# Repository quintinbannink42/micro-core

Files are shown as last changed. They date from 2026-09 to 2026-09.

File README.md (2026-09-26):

# Micro Core

Core EFI Hellen-One rusEFI ECU. Microsquirt-class sealed box, 35-way AMPSEAL, **vertical header**.

4-cylinder sequential wire-in. **STM32F407VGT6** on Hellen `mega-mcu100/0.3` (not mega-mcu64). Seven NCE4080K power FETs: 4 injector channels (2× high-Z each) plus fuel-pump, idle, and boost low-sides with US1M flyback and SMAJ33A. Gates are driven from `/V12_RAW` by SLM27524CA-DG low-side drivers, not directly from the 3.3 V GPIO.

## Status

Spec locked in [docs/SPEC.md](docs/SPEC.md). Hardware on this branch: **rev q**. Q1–Q7 are NCE4080K (LCSC C191380) on the existing DPAK land. Four SLM27524CA-DG drivers (LCSC C2921387) take the mega-mcu100 GPIO and drive the gates from `/V12_RAW` through the 12 ohm series resistors. Seven of eight channels are used; the spare input is tied to GND. Q5–Q7 (AMPSEAL pins 8/9/10, FP / Idle / Boost) keep the US1M flyback and SMAJ33A from rev p. F407VGT6 on mega-mcu100 stays. `boards/microcore-q/` lands when Create Board succeeds on `main` after merge. See [docs/HARDWARE_STATUS_rev_q.md](docs/HARDWARE_STATUS_rev_q.md). **Not production-ready.** The earlier FET comparison is in [docs/FET_COMPARISON.md](docs/FET_COMPARISON.md).

- Header: TE **776231-1** (straight / vertical)
- Plug: TE **776164-1** black, key A
- Not 776163-1 (right-angle)
- USB: vertical Mini-B on the frame (`hellen-one-common:USB_B_Mini` / `USB-MINI-B-VERTICAL`), gasketed flap or pigtail — not on the 35-way AMPSEAL

## Spec

See [docs/SPEC.md](docs/SPEC.md). Boss brief: [MICROCORE_BRIEF.md](MICROCORE_BRIEF.md).

Hellen tips: [docs/HELLEN-FAQ.md](docs/HELLEN-FAQ.md).

Firmware board name: `coreefi_micro` (sibling tree `/workspace/fw-coreefi-micro`, not in this repo). The MCU is the F407 from rev n; that firmware tree will need an F407 target later. This repo does not publish a firmware remote.

KiCad board basename: `microcore` (`BOARD_PREFIX=micro`, `BOARD_SUFFIX=core`, rev `q`).

## Hellen tooling

- Submodules: `hellen-one` (andreika-git/hellen-one), `kicad6-libraries` (rusefi/kicad6-libraries)
- CI: Create Board on push to `main`; daily submodule update workflows
- Fab outputs on main include `boards/microcore-p/`. After merge, Create Board writes `boards/microcore-q/`
- Local DRC needs **KiCad 10** (`kicad-cli`); board file is generator_version 10.0
- Empty-PCB guard: `bin/check-pcb-not-empty.sh` (Create Board job `guard-pcb-not-empty`)

## License

Hardware and docs in this repo: use for Core EFI product development.
Firmware will track rusEFI (GPL) when the board config lands.

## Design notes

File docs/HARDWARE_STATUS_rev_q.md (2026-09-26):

# Micro Core hardware status — rev q

**Date:** 2026-09-26
**Repo:** `quintinbannink42/micro-core`
**KiCad basename:** `microcore` (`BOARD_PREFIX=micro`, `BOARD_SUFFIX=core`)
**BOARD_REVISION:** **q** (fab-affecting: Q1–Q7 back to NCE4080K; four SLM27524 gate drivers on `/V12_RAW`)
**Create Board artifacts:** `boards/microcore-q/` is on `main`. Create Board has been green. This follow-up does not commit a fab pack.

## Verdict

**Not production-ready. Do not order boards.** `boards/microcore-q/` is on `main` and Create Board has been green. A human still has to look at the rev q gate-driver copper (B.Cu, U1–U4) and the GND stitch at `(131.3, 82)` before an order. Hellen DRC noise is accepted.

The electrical change is the one rev p left open: the MCU no longer drives the FET gates at 3.3 V. Each used channel is MCU GPIO to a SLM27524 input, driver output through the existing 12 ohm resistor, then the NCE4080K gate. Driver VDD is the vehicle `/V12_RAW` rail already on the board. No boost converter was added.

LS clamps from rev p are unchanged (D9–D11 US1M, D12–D14 SMAJ33A, injector D1–D8, ballast R8–R11). Frame short fixes from rev p are unchanged. Hellen module internals (M1/M2/M3) were not edited. Drill origin is still Edge.Cuts bottom-left `(107.5, 148.0872)`. `U105` stays STM32F407VGT6 on mega-mcu100.

## What landed (rev q)

### 1. Power FET: AOD4184A back to NCE4080K

Q1–Q7 are **NCE4080K**, LCSC **C191380**, footprint `microcore-fp:DPAK` (same land as rev p). Pinout stays gate, drain tab, source. AOD4184A / C99124 rows are gone from `bom_replace_microcore-q.csv`.

NCE4080K publishes RDS(on) at VGS = 10 V, not at 3.3 V. Rev q does not ask the 3.3 V GPIO to make that rating. The gate driver does.

### 2. Gate drivers

Four **Sillumin SLM27524CA-DG**, LCSC **C2921387**, SOIC-8, UCC27524 / UCC27524A class. Dual non-inverting low-side MOSFET drivers. Datasheet class: 4.5–20 V VDD, TTL/CMOS inputs (3.3 V is a valid high), about 4.5 A / 5.5 A peak. JLCPCB/LCSC had stock, so the TI UCC27524ADR alternate was not used.

Footprints are vendored as `microcore-fp:SOIC-8` and `microcore-fp:C0603` (3D models stripped). Drivers sit on **B.Cu**, next to the gate resistors. The front copper between the M1 keepout and the DPAKs does not have room for a SOIC.

| Driver | Channel | MCU net | Input | Output | Gate R | FET |
|---|---|---|---|---|---|---|
| U1 | B | `/OUT_INJ1` | pin 4 INB | pin 5 OUTB | R1 | Q1 |
| U1 | A | `/OUT_INJ2` | pin 2 INA | pin 7 OUTA | R2 | Q2 |
| U2 | B | `/OUT_INJ3` | pin 4 INB | pin 5 OUTB | R3 | Q3 |
| U2 | A | `/OUT_INJ4` | pin 2 INA | pin 7 OUTA | R4 | Q4 |
| U3 | B | `/OUT_LS1` | pin 4 INB | pin 5 OUTB | R5 | Q5 |
| U3 | A | `/OUT_LS2` | pin 2 INA | pin 7 OUTA | R6 | Q6 |
| U4 | B | `/OUT_LS3` | pin 4 INB | pin 5 OUTB | R7 | Q7 |
| U4 | A | unused | pin 2 INA tied to GND | pin 7 OUTA no-connect | — | — |

**7 of 8 channels used.** The unused input is tied low. It is not left floating.

ENA and ENB (pins 1 and 8) and VDD (pin 6) are on **`/V12_RAW`**. Driver GND (pin 3) is the same `GND` net as the FET sources. No new ground island.

Local ceramics at each VDD pin, to GND:

| Refs | Value | LCSC | Note |
|---|---|---|---|
| C1, C3, C5, C7 | 100 nF | C14663 | YAGEO CC0603KRX7R9BB104, already used on this board |
| C2, C4, C6, C8 | 1 uF 50 V X7R | **C559769** | YAGEO CC0603KRX7R9BB105. Samsung CL10A105KB8NNNC / C15849 was out of stock |

### 3. Kept from rev p

- D9–D11 US1M C112545, D12–D14 SMAJ33A C143131 on Q5–Q7. Injector D1–D8 and ballast R8–R11 unchanged.
- Frame copper short fixes (INJ3 / VR_OUT, VR_N vs drains, Q4/R9, and the rest of that pass).
- Drill origin `(107.5, 148.0872)`. Empty-PCB CI guard. ASCII-only `bom_replace` comments.
- U105 STM32F407VGT6 / mega-mcu100.

## DRC summary (kicad-cli 10.0.6)

Command: `kicad-cli pcb drc --format json --severity-all --units mm --schematic-parity`

The first rev q board matched rev p on 2026-09-26: 473 violations (207 error / 266 warning), 2 unconnected, 222 schematic-parity issues. Later passes, same checker:

- PR #11 stitched the F.Cu GND island. Unconnected 2→1. Violation count stayed 473.
- PR #12 cleared frame silk and the duplicate `/INJ1` via. Violations 473→400 (207 error / 193 warning). Unconnected stayed 1 (M2 pad S1).
- This follow-up moved Q2's reference off the M3 silk. `silk_overlap` 1→0. Violations 400→399 (207 error / 192 warning). Unconnected stays 1. Schematic parity stays 222. Hellen categories did not move. The 28 `silk_over_copper` hits are all M2 (left as later / ignore).

| Category | Now |
|---|---:|
| Total violations | 399 (207 error / 192 warning) |
| Unconnected items | 1 (M2 pad S1 vs F.Cu GND) |
| schematic_parity | 222 |
| items_not_allowed | 199 |
| padstack | 159 |
| silk_over_copper | 28 (M2 only) |
| shorting_items | 4 (Hellen pad-G pairs) |
| lib_footprint_issues | 5 |
| clearance | 2 |
| solder_mask_bridge | 1 |
| copper_edge_clearance | 1 |
| silk_overlap | 0 |
| tracks_crossing | 0 |

The items_not_allowed identity that changed in the original rev q pass is the `/OUT_INJ1` inner track. Rev p ended that trace on a via sitting on R1. Rev q removed that via (it would short the new driver-output net on the resistor pad) and shortened the trace from 3.6 mm to 2.125 mm. The remaining segment still enters the M1 keepout, which the old trace already did. Count stays 199. Hellen `items_not_allowed`, padstack, and pad-G shorts were not chased.

New copper was checked for shorts before save. The router refuses to write the board if a driver input, a driver output, or `/V12_RAW` does not join.

## Layout caveats

- Drivers and bypass caps are on B.Cu. A front SOIC does not fit between the M1 east pins and the gate resistors without sitting in the Hellen keepout.
- `/V12_RAW` is the B.Cu rail already at `(154.8, 110.4)`. A spine at x = 167.75 feeds U1–U3. That spine splits the back GND pour, so a stitch via at `(158.6, 113.0)` ties the pocket south of the spine back to the front GND zone.
- U4 is southeast of the `/INJ2` diagonal. Its VDD crosses on F.Cu between two vias, then drops back to B.Cu at the driver. Enables are tied to VDD on the chip.
- R6 (U3 OUTA) cannot cross Q3's drain on F.Cu or `/VR_N` on B.Cu. It leaves on B.Cu just west of the drain, runs In1 north of the `/VR_N` south via, and returns to F.Cu at R6.
- Inner-layer MCU tracks for the old direct gate nets were kept. The through-vias that sat on R1, R2, R4, R6, and R7 were deleted so they would not short the driver outputs. The stubs past the new taps were trimmed.
- Reference silk for U1–U3 and C1–C8 was moved so the new parts do not add silk_over_copper or silk_overlap. Q2's reference was later unlocked and moved to `(1.1, -5.1)` so it clears the M3 south silk. M3 was not edited.

## Create Board / fab path

Workflow: `.github/workflows/create-board.yaml` runs on push to `main`, then `bin/check-pcb-not-empty.sh`, then `andreika-git/hellen-one` Create Board. It applies `bom_replace_microcore-q.csv` from `revision.txt`.

`boards/microcore-q/` is already on `main`. This follow-up does not commit a fab pack. The Q2 reference move is silkscreen only (no copper, net, or drill-origin change). The next Create Board run on `main` refreshes that silk in the gerbers.

## Leftovers — before ordering boards

1. Create Board `boards/microcore-q/` and the JLC BOM confirm — **done**. `boards/microcore-q/board/microcore-q-BOM-JLC.csv` shows NCE4080K / C191380 on Q1–Q7, SLM27524CA-DG / C2921387 on U1–U4, C14663 and C559769 on the bypass caps, STM32F407VGT6 / C12345 on U105, and the clamps (US1M / C112545, SMAJ33A / C143131).
2. Residual Hellen keepout / padstack / module pad-G / edge, plus M2 silk and M2 pad S1 — **accepted / ignore**. Owner table: [DRC_TRIAGE_rev_q.md](DRC_TRIAGE_rev_q.md).
3. Human copper review of the gate-driver copper (B.Cu, U1–U4) and the GND stitch at `(131.3, 82)` — **required before order**.
4. Firmware `coreefi_micro` F407 target in the sibling tree — out of scope.
5. Optional later: `footprint_symbol_mismatch` (32) left on purpose. Writing `microcore-fp:DPAK` / `R0603` / `DO214AC` on the embedded footprint clears that parity warning, then KiCad diffs the copy against `footprints/*.kicad_mod` and adds `lib_footprint_mismatch`.

## Incident guard

Do not whole-file-replace `microcore.kicad_pcb`. Guard: `bin/check-pcb-not-empty.sh` (min 10 kB + `(zone` present). Drill origin must stay Edge.Cuts bottom-left `(107.5, 148.0872)`.

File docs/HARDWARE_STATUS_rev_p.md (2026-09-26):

# Micro Core hardware status — rev p

**Superseded by rev q (2026-09-26).** Q1–Q7 are NCE4080K again, with SLM27524CA-DG gate drivers on `/V12_RAW`. See `docs/HARDWARE_STATUS_rev_q.md`.

**Date:** 2026-09-25  
**Repo:** `quintinbannink42/micro-core`  
**KiCad basename:** `microcore` (`BOARD_PREFIX=micro`, `BOARD_SUFFIX=core`)  
**BOARD_REVISION:** **p** (fab-affecting: Q1–Q7 FET swap to AOD4184A; LS flyback + TVS; frame short fixes)  
**Create Board artifacts:** `boards/microcore-o/` is on main from rev o. **`boards/microcore-p/` after this rev is merged to `main`** (Create Board on a PR branch may run but fab files land on `main` only).

## Verdict

**Not production-ready. Do not order boards.** Quintin chose **AOD4184A** (LCSC **C99124**) and TVS on the low-side channels for budget and reliability. Rev p puts that FET on all seven DPAK lands, adds the existing cheap injector clamps to Q5–Q7, and clears the real injector / VR shorts on frame copper. Hellen module noise is still there and is listed below.

`microcore.kicad_pcb` stays substantial (F.Cu+B.Cu GND zones refilled after the diode routes and two GND stitch vias). Drill origin unchanged: Edge.Cuts bottom-left `(107.5, 148.0872)`. Core EFI silkscreen kept; letter bumped to **rev P**.

## What landed (rev p)

### 1. Power FET: NCE4080K → AOD4184A

All seven frame power FETs (Q1–Q7) are **AOD4184A**, LCSC **C99124**. Same footprint: `microcore-fp:DPAK` (TO-252 land, not redrawn). Pinout stays pin 1 gate, pin 2 drain tab, pin 3 source. Quintin picked this part for budget and reliability.

`bom_replace_microcore-p.csv` rows (ASCII comments, no ohm symbol):

`Q1`…`Q7,"AOD4184A","DPAK","C99124"`

`U105` stays `STM32F407VGT6` / `LQFP100` / `C12345` on `mega-mcu100/0.3`. Not switched to mega-mcu64.

### 2. 3.3 V gate caveat

AOD4184A is a discrete MOSFET, not a protected smart FET. No gate driver was added.

- RDS(on) max **9.5 mohm at Vgs = 4.5 V**, ID = 15 A. Not specified at 3.3 V.
- VGS(th) max **2.6 V**, so a 3.3 V MCU pin does turn the FET on.
- RDS(on) at 3.3 V is not guaranteed, especially hot and at injector or fuel-pump current.

Each gate is still the existing 12 ohm resistor (R1–R7) from the mega-mcu100 output.

### 3. Low-side flyback + TVS (Q5–Q7)

Same cheap injector-class parts already on the board. No premium clamps. No series ballast on the LS channels. Proven clamps, not extra copper protection.

| Ref | Channel | AMPSEAL | Flyback | TVS |
|---|---|---|---|---|
| Q5 | Fuel pump | pin 8 `LS1_FP` | D9 US1M C112545 | D12 SMAJ33A C143131 |
| Q6 | Idle / VVT | pin 9 `LS2_IDLE` | D10 US1M C112545 | D13 SMAJ33A C143131 |
| Q7 | Boost / spare | pin 10 `LS3_BOOST` | D11 US1M C112545 | D14 SMAJ33A C143131 |

Electrical match to Q1–Q4: flyback anode on the LS net, cathode on `/V12_RAW`; TVS cathode on the LS net, anode on GND. Parts are DO-214AC on B.Cu, north of J1. D11 is shifted to x = 152.75 so its +12 pad clears the `/VR_OUT` via at `(153.5, 111.9)`.

Two GND stitch vias, `(115.5, 105.8)` and `(144.0, 114.6)`, tie the back-side pour pockets under D12 and D13 into the front GND pour. After refill those pockets are not unconnected items.

Injector protection is unchanged: D1–D4 US1M, D5–D8 SMAJ33A, ballast R8–R11.

### 4. Frame copper shorts that this pass cleared

KiCad DRC no longer reports these rev o shorts:

- `/INJ3` on In1 jogged off `/VR_OUT` (1.0 mm track at x = 175.6; a wider jog shorted `/SGND`).
- `Net-(Q1-D)` and `Net-(Q3-D)` orthogonal segments that hit `/VR_N` removed; the drain diagonals stay.
- R9 moved to `(188, 90)` and the `/INJ2` via moved onto the new pad so `Net-(Q4-D)` no longer shorts `Net-(Q2-D)`. The Q4/R9 solder-mask bridge and the 0.05 mm clearance are gone.

## DRC summary (kicad-cli **10.0.6**)

Command: `kicad-cli pcb drc --format json --severity-all --units mm --refill-zones --save-board`

`schematic_parity` is empty (sheet and board agree). Zones were refilled after the track retarget and the stitch vias.

| Category | Count | Triage |
|---|---:|---|
| **Total violations** | **473** | 207 error / 266 warning (rev o was 467: 217 error / 250 warning) |
| items_not_allowed | 199 | Hellen module keepout (M1/M2/M3) — unchanged |
| padstack | 159 | Hellen merge noise — unchanged |
| silk_over_copper | 81 | Was 65. The extra marks are D9–D14 back silk. Not chased |
| silk_overlap | 20 | Cosmetic / module — unchanged |
| **shorting_items** | **4** | Was 10. All four left are Hellen pad G vs an empty-net pad. No injector, no `/LS*`, no new diode short |
| clearance | 2 | Both M3 pad E4 `/V5_REF` vs empty pad G. Q4/R9 clearance is gone (rev o had 5) |
| lib_footprint_issues | 5 | Vendored / Hellen |
| solder_mask_bridge | 1 | M3 pad G vs E4 only (rev o had 2; Q4/R9 bridge is gone) |
| copper_edge_clearance | 1 | M3 pad G on In2 touches Edge.Cuts |
| holes_co_located | 1 | Duplicate via leftover (Hellen) |
| **unconnected_items** | **2** | Same class as rev o: M2 pad S1 keepout vs F.Cu GND, and one F.Cu GND island. Not Q1–Q7, not D9–D14, not J1 pins 8/9/10 |
| tracks_crossing | **0** | |
| track_dangling | **0** | |
| starved_thermal | **0** | |
| courtyards_overlap | **0** | |

### Hellen noise still present (do not edit M1/M2/M3 for these)

- `/VR_OUT` F.Cu `(184.15, 83.622)`–`(186, 81.772)` vs M3 pad G `<no net>` `(186.175, 82.265)`.
- M3 pad G GND `(178.725, 75.84)` vs empty pad G `(185.925, 72.64)`.
- M1 pad G GND `(133.28119, 76.67602)` vs empty pads `(133.28119, 79.72601)` and `(137.18119, 74.12602)`.
- Clearance 0 mm: M3 PTH E4 `/V5_REF` `(193.425, 73.04)` vs empty pad G on B.Cu and In1 `(186.025, 72.7775)`. Same pair is the remaining solder-mask bridge.
- Copper edge: M3 pad G on In2 `(185.7875, 72.74)` touches Edge.Cuts.
- Unconnected: M2 pad S1 `(109.850001, 87.15)` vs F.Cu GND inside the keepout, plus one F.Cu GND island.
- items_not_allowed 199, padstack 159, lib_footprint_issues 5, holes_co_located 1.

**Not a fab order.** Create Board `boards/microcore-p/` is still required after merge. The 3.3 V gate vs 4.5 V RDS(on) caveat is still open; this rev does not add a gate driver.

## Create Board / fab path

Workflow: `.github/workflows/create-board.yaml`

1. `on: push` and `workflow_dispatch`
2. Job `guard-pcb-not-empty` runs `bin/check-pcb-not-empty.sh microcore.kicad_pcb`
3. Reuses `andreika-git/hellen-one/.github/workflows/create-board.yaml@master`, which applies `bom_replace_microcore-p.csv`

**Exact next step for CI artifacts:** merge this branch to default **`main`**. Fab files are committed by that reusable workflow **on `main` only**.

## Leftovers — before ordering boards

1. Green Create Board `boards/microcore-p/` and confirm the JLC BOM shows `AOD4184A` / `C99124` on Q1–Q7, `STM32F407VGT6` / `C12345` on `U105`, D9–D11 US1M, and D12–D14 SMAJ33A.
2. The 3.3 V gate does not have an RDS(on) spec. The datasheet number is at 4.5 V. A driver is not on this rev.
3. Residual Hellen keepout / padstack / module pad G / edge noise listed above.
4. Firmware `coreefi_micro` F407 target in the sibling tree (not this PR). This repo does not publish firmware.

## Incident guard

Do not whole-file-replace `microcore.kicad_pcb`. Guard: `bin/check-pcb-not-empty.sh` (min 10 kB + `(zone` present). Drill origin must stay Edge.Cuts bottom-left `(107.5, 148.0872)`.

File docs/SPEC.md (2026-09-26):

# Micro Core — product spec (rev P, 2026-09-24)

First Core EFI Hellen-One ECU.

**Name:** Micro Core  
**Form:** Microsquirt-class sealed box  
**Connector:** 35-way AMPSEAL, **vertical header**  
**Brain:** rusEFI Hellen-One / **STM32F407VGT6** on `mega-mcu100/0.3` (not mega-mcu64)  
**Job:** 4-cylinder sequential wire-in

## Header (locked)
**Vertical / straight pins.** Header stands off the PCB. Plug mates from above. Cable leaves the **top** of the case.

| | Part |
|---|---|
| PCB header | TE **776231-1** (35-pos AMPSEAL header, straight / vertical) |
| Mating plug | TE **776164-1** (black, key A) |
| Contacts | 1.3 mm, 17 A max |
| Orientation | AMPSEAL on the lid face, same language as V3 Microsquirt |

Do not use 776163-1 (right-angle). That puts the plug off the board edge.

Keepout: header body + plug + strain-relief is the tallest stack on the board. Route FETs and crystals away from that courtyard. Lid has a rectangular cut / well for the header flange and seal.

## Envelope
| | Target |
|---|---|
| Case L × W × H | ~120 × 80 × 42 mm including AMPSEAL height |
| Mounting | two tabs, ~107 × 54 mm centres, Ø5 mm |
| PCB | ~90 × 60 mm including header keepout |
| MAP | external |
| USB | gasketed flap or pigtail, not on the 35-way |

## AMPSEAL I/O (35 pins)
4 inj, 8 logic coils (IGN1–8), 3 PGND, 2 SGND, +12, 5 V, CLT, IAT, MAP, TPS, VR crank ±, Hall cam, CAN H/L, 2× DIN, 2× analog spare. Pins 8/9/10 are the low-side outputs (fuel pump, idle / VVT, boost / spare).

No ETB and no onboard LSU on this connector.

### Draft pin map
| Pin | Function |
|---|---|
| 1 | +12 V switched |
| 2 | CAN H |
| 3 | CAN L |
| 4–7 | Injector 1–4 |
| 8 | Fuel pump LS (Q5) |
| 9 | Idle / VVT LS (Q6) |
| 10 | Boost / spare LS (Q7) |
| 11 | DIN1 (IN_D1 / PE12) |
| 12–15 | Ignition 1–4 (5 V) |
| 16 | +5 V ref |
| 17 | TPS |
| 18 | MAP |
| 19 | Analog spare 1 |
| 20 | Sensor ground |
| 21 | Analog spare 2 |
| 22–23 | Power ground |
| 24 | CLT |
| 25 | IAT |
| 26 | DIN2 (IN_D2 / PE13) |
| 27 | Hall cam |
| 28 | VR crank + |
| 29 | VR crank − |
| 30 | IGN5 (PE2) |
| 31 | IGN6 (PB8) |
| 32 | IGN7 (PB9) |
| 33 | IGN8 (PE6) |
| 34 | SGND |
| 35 | PGND |

Core pinout, not a Microsquirt copy.

## Power stage
7× DPAK-class N-FET, all **NCE4080K** (TO-252, LCSC **C191380**) on the existing `microcore-fp:DPAK` land. The land is not redrawn. Rev q restored this FET after rev p's AOD4184A trial and added a gate driver so the 3.3 V GPIO is not the gate voltage.

Gate path, each used channel: mega-mcu100 GPIO to a **SLM27524CA-DG** input (LCSC **C2921387**, UCC27524-class dual non-inverting low-side driver), driver output through the existing 12 ohm gate resistor (R1–R7), then the FET gate. Four SOIC-8 drivers give eight channels; seven drive Q1–Q7 and U4 channel A has its input tied to GND. Driver VDD, and both enable pins, are the existing **`/V12_RAW`** rail (about 12 V on the gate). Each driver has 100 nF (C14663) and 1 uF (C559769) from VDD to the same GND as the FET sources. No boost converter.

4× injector (Q1–Q4) + SMAJ33A + US1M flyback. Two 12 ohm high-Z per channel (gate R1–R4 + ballast R8–R11). FETs on the lid-facing copper, gap-pad, clear of the AMPSEAL well.

3× low-side (Q5 fuel pump, Q6 idle / VVT, Q7 boost / spare) with gate R5–R7 at 12 ohm, plus the same cheap injector clamps per channel: US1M flyback (anode on the LS net, cathode on +12 V) and SMAJ33A (cathode on the LS net, anode on GND). No series ballast on Q5–Q7. No premium clamps. Pins 8/9/10 are those drains.

NCE4080K is a discrete MOSFET, not a protected smart FET. Its RDS(on) figure is at VGS = 10 V. The driver, not the MCU pin, is what gets the gate there. See `docs/HARDWARE_STATUS_rev_q.md`.

## Hellen modules
MCU **STM32F407VGT6** (LQFP100, LCSC **C12345**) inside Hellen `mega-mcu100/0.3`. Do not switch to `mega-mcu64`. Input lite (1× VR + Hall + analog), 4-ch Core injectors, 4-ch 5 V ign, power, 3× LS. Knock / WBO as pads or CAN.

`bom_replace_microcore-q.csv` keeps `U105` `STM32F407VGT6` / `C12345`, sets Q1–Q7 to `NCE4080K` / `C191380`, and adds U1–U4 `SLM27524CA-DG` / `C2921387` plus the VDD bypass caps. D9–D11 are US1M / C112545 and D12–D14 are SMAJ33A / C143131. C15815 and C2252 are not this MCU (op-amp and 22.1184 MHz crystal).

Firmware board: `coreefi_micro` (sibling tree `/workspace/fw-coreefi-micro`, not published from this hardware repo). That tree will need an **F407** target later; this rev does not add a firmware remote.

## Frame controls (rev K)

mega-mcu100 already has internal tactile switches (S100 nReset, S101 BOOT0). **Frame SW_BOOT / SW_RESET were removed in rev k** (schematic + PCB) so they no longer parallel those module buttons. Boot/reset on the sealed box is module-only unless a later rev adds external switches again.

## Analog / Hall conditioning (waiver — rev H)

Frame sheets `ANALOG.kicad_sch` / `HALL.kicad_sch` remain hierarchy passthrough stubs.

**Accepted for Micro Core v1:** sensor conditioning is **mega-module-only** via Hellen `mega-mcu100` input lite (1× VR + Hall + analog paths on the module). No additional frame dividers / pull-ups / ESD required for fab of the first sealed-box rev, unless a later product change reopens this.

Firmware pin freeze still follows this SPEC + `fw-coreefi-micro/connectors/main.yaml`.

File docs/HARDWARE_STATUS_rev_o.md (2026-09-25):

# Micro Core hardware status — rev o

**Superseded by rev p (2026-09-25).** Quintin chose AOD4184A (LCSC C99124) plus LS US1M flyback and SMAJ33A for budget and reliability. See `docs/HARDWARE_STATUS_rev_p.md`.

**Date:** 2026-09-22  
**Repo:** `quintinbannink42/micro-core`  
**KiCad basename:** `microcore` (`BOARD_PREFIX=micro`, `BOARD_SUFFIX=core`)  
**BOARD_REVISION:** **o** (fab-affecting: power FET swap to NCE4080K; LS Q5–Q7 and R5–R7 restored)  
**Create Board artifacts:** `boards/microcore-n/` is on main from rev n. **`boards/microcore-o/` after this rev is merged to `main`** (Create Board on a PR branch may run but fab files land on `main` only).

## Verdict

**Not production-ready.** Rev o puts NCE4080K on all seven power FETs and brings the low-side stage back. Do not order boards until Create Board produces `boards/microcore-o/` and a human accepts the gate-drive caveat below.

`microcore.kicad_pcb` stays substantial (F.Cu+B.Cu GND zones kept; refill after the LS restore is recorded below). Drill origin unchanged: Edge.Cuts bottom-left `(107.5, 148.0872)`. Core EFI silkscreen kept; letter bumped to **rev O**.

## What landed (rev o)

### 1. Power FET: VND14NV04-E → NCE4080K

All seven frame power FETs (Q1–Q7) are **NCE4080K**, LCSC **C191380**.

LCSC check (2026-09-22), page https://www.lcsc.com/product-detail/C191380.html :

| ID | What LCSC lists | Used? |
|---|---|---|
| **C191380** | NCE **NCE4080K**, MOSFET N-CH 40 V 80 A, package **TO-252-2L**, in stock (page showed about 21,877) | **Yes** |

Datasheet (LCSC PDF, NCE V2.0): VDS 40 V, ID 80 A, VGS ±20 V, VGS(th) 1.2 / 1.8 / 2.5 V (min / typ / max) at ID = 250 µA, RDS(on) < 7 mΩ at VGS = 10 V and ID = 20 A. No RDS(on) row at 4.5 V or 2.5 V.

`bom_replace_microcore-o.csv` rows (ASCII comments, no ohm symbol):

`Q1`…`Q7,"NCE4080K","DPAK","C191380"`

`U105` stays `STM32F407VGT6` / `LQFP100` / `C12345` on `mega-mcu100/0.3`. Not switched to mega-mcu64.

### 2. Footprint: existing DPAK land fits TO-252-2L

PCB footprint is still `microcore-fp:DPAK` (file `footprints/DPAK.kicad_mod`). It is a 2-lead + tab pattern, not a 3-lead gullwing:

| | Existing `DPAK` | LCSC EasyEDA land for C191380 (`TO-252-2_L6.6-W6.1-P4.57-LS9.9-BR-CW`) |
|---|---|---|
| Lead pitch | 4.56 mm (pads at y = ±2.28 mm) | **P4.57** (4.57 mm) |
| Lead pads | 2.2 × 1.2 mm | about 3.0 × 1.6 mm |
| Tab (drain) | 6.4 × 5.8 mm | about 6.2 × 5.8 mm |

Package body from the NCE drawing: lead width b = 0.66–0.86 mm, basic pitch e = 2.186–2.386 mm (JEDEC; the 2L part keeps the outer leads, so the span is about 2×e). The datasheet note says the lead pitch follows JEDEC. Pinout on the LCSC symbol is pin 1 Gate, pin 2 Drain (tab), pin 3 Source. That matches the footprint pads and the schematic symbol pin numbers already used for the old smart FET (1 = input/gate, 2 = drain, 3 = source).

The lead is narrower than the 1.2 mm pad. The lead pad is smaller than LCSC’s recommended land, and the pitch and tab match, so the footprint was **not** redrawn. Routing that already landed on these pads stays put.

### 3. Seven FETs: Q5–Q7 and R5–R7 restored

Rev n deleted the low-side stage. Rev o puts it back from the pre-rev-n sheet and copper:

| Ref | Role | Gate | AMPSEAL |
|---|---|---|---|
| Q5 | Fuel-pump LS | R5, 12 ohm | pin 8 `LS1_FP` |
| Q6 | Idle / VVT LS | R6, 12 ohm | pin 9 `LS2_IDLE` |
| Q7 | Boost / spare LS | R7, 12 ohm | pin 10 `LS3_BOOST` |

`LS3.kicad_sch` is the three-channel sheet again (hierarchical IN1–IN3 / OUT1–OUT3). Root sheet name is `LS3` (not `LS3-NC`). MCU labels `OUT_LS1` / `OUT_LS2` / `OUT_LS3` connect to the gates through R5–R7. J1 pads 8/9/10 carry `/LS1_FP` `/LS2_IDLE` `/LS3_BOOST` again.

LS still has **no** flyback diode and **no** TVS. That matches the pre-rev-n sheet (the note there already said flyback/TVS were injector-only). Injector protection is unchanged: D1–D4 US1M, D5–D8 SMAJ33A, ballast R8–R11, all on Q1–Q4.

### 4. NCE4080K is not a protected smart FET — gate drive caveat

VND14NV04-E was a logic-level protected low-side (current limit, thermal shutdown, internal clamp) that a 3.3 V MCU can drive directly. NCE4080K is a plain trench MOSFET.

- **The schematic is complete without a gate driver.** VGS(th) max is 2.5 V, and the MCU pin is 3.3 V, so the FET does turn on. Each gate is the existing 12 ohm series resistor (R1–R7) from the mega-mcu100 output. No driver, charge pump, or extra transistor was added.
- **The 7 mΩ rating does need ~10 V if you want that RDS(on).** The datasheet gives RDS(on) only at VGS = 10 V. At 3.3 V the worst-case device is 0.8 V above threshold. On-resistance at 3.3 V is not specified and will be higher than 7 mΩ, especially hot and at injector or fuel-pump current. A gate driver to about 10 V, or a different MOSFET with RDS(on) rated at 4.5 V or below, is required before this is a reliable power stage. That driver is **not** on this rev.
- **No internal clamp.** Injector channels still have US1M flyback and SMAJ33A. The three LS channels do not. Fuel-pump, idle, and boost solenoids are inductive. The only voltage limit on those drains is the 40 V FET itself.

## DRC summary (kicad-cli **10.0.6**)

Command: `kicad-cli pcb drc --format json --severity-all --units mm --refill-zones --save-board`

F.Cu+B.Cu GND zones were refilled after Q5–Q7 and R5–R7 were put back, so the new gate and drain pads are cleared out of the pour and the source pads sit on GND. Fill diff is polygon geometry. Footprints, drill origin `(107.5, 148.0872)`, and zone outlines were not moved. `schematic_parity` is empty (sheet and board agree).

| Category | Count | Triage |
|---|---:|---|
| **Total violations** | **467** | 217 error / 250 warning (rev n was 456: 217 / 239; rev m was 469: 219 / 250) |
| items_not_allowed | 199 | Hellen module keepout (M1/M2/M3) — merge noise |
| padstack | 159 | Hellen merge noise |
| silk_over_copper | 65 | Back to the rev m count; LS ref silk is on the board again (rev n was 56) |
| silk_overlap | 20 | Cosmetic / module (rev n was 18) |
| **shorting_items** | **10** | Same count as rev n. **No LS net** (`/LS*`, `Net-(Q5-IN)` …) |
| clearance | 5 | FET cluster / merge; same class as rev n |
| lib_footprint_issues | 5 | Vendored / Hellen |
| solder_mask_bridge | 2 | Same class as rev n (Q4/R9 injector side, not the restored LS FETs) |
| copper_edge_clearance | 1 | Edge |
| holes_co_located | 1 | Duplicate via leftover (Hellen) |
| **unconnected_items** | **2** | M2 pad S1 keepout vs F.Cu GND; one F.Cu GND island. **Not** Q5–Q7 and **not** J1 pins 8/9/10 |
| tracks_crossing | **0** | |
| via_dangling | **0** | |

### Shorts still present (rev n / rev m leftovers, not this pass)

- `/INJ3`↔`/VR_OUT` on In1 (Hellen leftover fanout vs VR).
- `/VR_N`↔`Net-(Q1-D)` and `/VR_N`↔`Net-(Q3-D)`.
- `Net-(Q4-D)`↔`Net-(Q2-D)` (injector ballast, not Q5–Q7).
- GND or `/VR_OUT` vs an empty-net module pad.

No short names `/LS1_FP`, `/LS2_IDLE`, `/LS3_BOOST`, or `Net-(Q5-IN)` / `Q6` / `Q7`.

Q5 pads after refill: gate `Net-(Q5-IN)`, drain `/LS1_FP`, source `GND`. Q6/Q7 follow the same pattern (idle, boost).

**Not a fab order yet.** Create Board `boards/microcore-o/` and a human decision on 3.3 V gate drive vs the 10 V RDS(on) rating are still required. The DRC blockers above are the preexisting Hellen merge / injector-VR shorts, not the FET swap or the restored LS stage.

## Create Board / fab path

Workflow: `.github/workflows/create-board.yaml`

1. `on: push` and `workflow_dispatch`
2. Job `guard-pcb-not-empty` runs `bin/check-pcb-not-empty.sh microcore.kicad_pcb`
3. Reuses `andreika-git/hellen-one/.github/workflows/create-board.yaml@master`, which applies `bom_replace_microcore-o.csv`

**Exact next step for CI artifacts:** merge this branch to default **`main`**. Fab files are committed by that reusable workflow **on `main` only**.

## Leftovers — before ordering boards

1. Green Create Board `boards/microcore-o/` and confirm the JLC BOM shows `NCE4080K` / `C191380` on Q1–Q7, `STM32F407VGT6` / `C12345` on `U105`, and R5–R7 present.
2. Decide the 3.3 V gate vs 10 V RDS(on) question (driver, or a logic-level FET) before relying on injector or fuel-pump current. Comparison and recommendation (keep NCE4080K; DMTH4004LK3 is the wrong swap at 3.3 V): [FET_COMPARISON.md](FET_COMPARISON.md).
3. LS inductive loads have no external clamp.
4. Residual Hellen keepout / padstack noise and the preexisting injector-VR shorts called out on rev n.
5. Firmware `coreefi_micro` F407 target in the sibling tree (not this PR). This repo does not publish firmware.

## Incident guard

Do not whole-file-replace `microcore.kicad_pcb`. Guard: `bin/check-pcb-not-empty.sh` (min 10 kB + `(zone` present). Drill origin must stay Edge.Cuts bottom-left `(107.5, 148.0872)`.

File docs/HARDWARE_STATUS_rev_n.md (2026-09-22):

# Micro Core hardware status — rev n

**Date:** 2026-09-22  
**Repo:** `quintinbannink42/micro-core`  
**KiCad basename:** `microcore` (`BOARD_PREFIX=micro`, `BOARD_SUFFIX=core`)  
**BOARD_REVISION:** **n** (fab-affecting: F407 BOM swap on mega-mcu100; remove LS FET stage)  
**Create Board artifacts:** last packages on main include `boards/microcore-m/`. **`boards/microcore-n/` after this rev is merged to `main`** (Create Board on a PR branch may run but fab files land on `main` only).

## Verdict

**Not production-ready.** Cost-down rev n keeps Hellen `mega-mcu100/0.3` and swaps the module MCU from STM32F429VIT6 to STM32F407VGT6. The frame low-side FET stage is removed. Do not order boards until Create Board produces `boards/microcore-n/` and a human reviews the JLC BOM line for `U105`.

`microcore.kicad_pcb` stays substantial (filled F.Cu+B.Cu GND zones still present). Drill origin unchanged: Edge.Cuts bottom-left `(107.5, 148.0872)`. Core EFI silkscreen kept; letter bumped to **rev N**.

## What landed (rev n)

### 1. MCU: F429 → F407, same mega-mcu100

Module symbol stays `Module:mega-mcu100/0.3` / footprint `hellen-one-mega-mcu100-0.3:mega-mcu100`. Not switched to mega-mcu64.

`bom_replace_microcore-n.csv` row:

`U105,"STM32F407VGT6","LQFP100","C12345"`

Replaces `STM32F429VIT6` / LCSC `C92002` (the `U105` line in `boards/microcore-m/board/microcore-m-BOM-JLC.csv`).

LCSC check (2026-09-22):

| ID | What LCSC/JLCPCB actually lists | Used? |
|---|---|---|
| **C12345** | ST **STM32F407VGT6**, LQFP-100(14x14), 1 MB flash, in stock (LCSC showed 1601) | **Yes** |
| C15815 | TI TLC2252CDR op-amp, SOP-8 | No |
| C2252 | YXC 22.1184 MHz crystal, HC-49S-SMD | No |

Firmware board name remains `coreefi_micro`. Sibling tree `/workspace/fw-coreefi-micro` will need an F407 target later. This hardware repo does not add a firmware remote.

### 2. Four injector FETs only

Kept: Q1–Q4, gate R1–R4, ballast R8–R11, flyback D1–D4 (US1M), TVS D5–D8 (SMAJ33A).

Removed from schematic (`LS3.kicad_sch` is now a stub, root sheet `LS3-NC` has no pins) and from the PCB (footprints, tracks, vias, ref silk):

| Was | Role | Gate resistor |
|---|---|---|
| Q5 | Fuel-pump LS | R5 |
| Q6 | Idle / VVT LS | R6 |
| Q7 | Boost / spare LS | R7 |

Copper deleted with those parts (no remaining segments or vias):

- `/LS1_FP`, `/LS2_IDLE`, `/LS3_BOOST` (drains to AMPSEAL)
- `Net-(Q5-IN)`, `Net-(Q6-IN)`, `Net-(Q7-IN)` (gate side of R5–R7)
- `/OUT_LS1`, `/OUT_LS2`, `/OUT_LS3` tracks and vias

mega-mcu100 pads E18/E19/E20 still carry nets `/OUT_LS1` `/OUT_LS2` `/OUT_LS3` (module pins OUT_PWM1/2/3). Those pads are the module footprint, not traces to the removed FETs. J1 pads 8/9/10 have the LS nets cleared (connector pin copper only, no tracks).

No explicit GND track ended on the Q5–Q7 source pads (sources were on the GND pour). Diode GND stubs at x=195.1 (rev m) were left in place.

`bom_replace_microcore-n.csv` drops the Q5–Q7 and R5–R7 rows. Comments are ASCII-only.

### 3. AMPSEAL pins 8/9/10

| Pin | rev m | rev n |
|---|---|---|
| 8 | Fuel pump LS | Reserved / NC (unstuffed LS — future option) |
| 9 | Idle / VVT LS | Reserved / NC (unstuffed LS — future option) |
| 10 | Boost / spare LS | Reserved / NC (unstuffed LS — future option) |

Schematic: local labels `LS1_FP` / `LS2_IDLE` / `LS3_BOOST` removed from J1; `no_connect` on those pins.

## DRC summary (kicad-cli **10.0.6**)

Command: `kicad-cli pcb drc --format json --severity-all --units mm --refill-zones --save-board`

F.Cu+B.Cu GND zones were refilled after the LS deletion. Fill diff is polygon geometry only (footprints, drill origin, and zone outlines unchanged).

| Category | Count | Triage |
|---|---:|---|
| **Total violations** | **456** | 217 error / 239 warning (rev m was 469: 219 / 250) |
| items_not_allowed | 199 | Hellen module keepout (M1/M2/M3) — merge noise |
| padstack | 159 | Hellen merge noise |
| silk_over_copper | 56 | Was 65 on rev m (LS ref silk gone) |
| silk_overlap | 18 | Cosmetic / module |
| **shorting_items** | **10** | Was 12 on rev m. **No LS net** (`/LS*`, `Net-(Q5-IN)` …) remains |
| clearance | 5 | FET cluster / merge; not the removed LS stage |
| lib_footprint_issues | 5 | Vendored / Hellen |
| solder_mask_bridge | 2 | Same class as rev m (not the removed FETs) |
| copper_edge_clearance | 1 | Edge |
| holes_co_located | 1 | Duplicate via leftover (Hellen), same class as rev m |
| **unconnected_items** | **2** | M2 pad S1 keepout vs F.Cu GND; one F.Cu GND island. **Not** J1 pins 8/9/10 |
| tracks_crossing | **0** | |
| via_dangling | **0** | LS vias removed with their nets |

### Shorts still present (rev m leftovers, not this pass)

- `/INJ3`↔`/VR_OUT` on In1 (Hellen leftover fanout vs VR).
- `/VR_N`↔`Net-(Q1-D)` and `/VR_N`↔`Net-(Q3-D)`.
- `Net-(Q4-D)`↔`Net-(Q2-D)`.
- GND or `/VR_OUT` vs an empty-net module pad.

No short names `/LS1_FP`, `/LS2_IDLE`, `/LS3_BOOST`, or `Net-(Q5-IN)` / `Q6` / `Q7`.

**Not a fab order yet.** Create Board `boards/microcore-n/` and a human look at the JLC `U105` line are still required. The DRC blockers above are the preexisting Hellen merge / injector-VR shorts, not the F407 swap or the removed LS stage.

## Create Board / fab path

Workflow: `.github/workflows/create-board.yaml`

1. `on: push` and `workflow_dispatch`
2. Job `guard-pcb-not-empty` runs `bin/check-pcb-not-empty.sh microcore.kicad_pcb`
3. Reuses `andreika-git/hellen-one/.github/workflows/create-board.yaml@master`, which applies `bom_replace_microcore-n.csv`

**Exact next step for CI artifacts:** merge this branch to default **`main`**. Fab files are committed by that reusable workflow **on `main` only**.

## Leftovers — before ordering boards

1. Green Create Board `boards/microcore-n/` and confirm JLC BOM shows `STM32F407VGT6` / `C12345` on `U105`, and that Q5–Q7 / R5–R7 are absent.
2. Residual Hellen keepout / padstack noise and the preexisting In1 `/INJ3`↔`/VR_OUT` short (rev m leftover). Zone refill for this rev is already in the board file.
3. Firmware `coreefi_micro` F407 target in the sibling tree (not this PR).

## Incident guard

Do not whole-file-replace `microcore.kicad_pcb`. Guard: `bin/check-pcb-not-empty.sh` (min 10 kB + `(zone` present). Drill origin must stay Edge.Cuts bottom-left `(107.5, 148.0872)`.

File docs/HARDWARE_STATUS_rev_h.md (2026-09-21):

> **Superseded for current work:** see [HARDWARE_STATUS_rev_m.md](HARDWARE_STATUS_rev_m.md) (rev m: D1–D8 collector re-route).

# Micro Core hardware status — rev h → i

**Date:** 2026-09-21 (UTC+2)  
**Repo:** `quintinbannink42/micro-core` @ `main`  
**KiCad basename:** `microcore` (`BOARD_PREFIX=micro`, `BOARD_SUFFIX=core`)  
**BOARD_REVISION:** **i** (PCB content change this pass: J8 GND stitch). Rev **h** was restore + Edge.Cuts origin `(107.5, 148.0872)`.  
**Create Board artifacts:** last green `boards/microcore-i/` (CI run 35559694730 success).

## Verdict

**Not fab-ready.** J8 GND stitch and FET/gate LCSC assigns landed; injector/LS flyback+TVS (+ second 12 Ω high-Z) still missing from schematic/PCB; remaining DRC noise is mostly Hellen keepout / empty-net module-pad merge.

## DRC summary (kicad-cli **10.0.6**)

Command: `kicad-cli pcb drc --format report --severity-all --output … microcore.kicad_pcb`  
(Board is KiCad 10 format; Debian kicad 9.0.2 cannot load it.)

### vs prior status (rev g doc, KiCad 9.0.2 on pre-merge style counts)

| Category | Rev g (K9 doc) | Rev i after J8 stitch (K10) | Notes |
|---|---:|---:|---|
| Total DRC violations | (large; mixed cats) | **425** | Different checker/taxonomy under K10 |
| shorting_items | **147** | **4** | No mass GND↔SGND pairs under K10; remaining = empty-net module pad G vs signal/GND |
| unconnected_items | **2** (zone island + **J8 GND**) | **1** | **J8 cleared**; leftover = F.Cu GND zone ↔ M2 pad S1 inside module keepout (copperpour/tracks not_allowed) — treat as Hellen-merge false positive unless copper review says otherwise |
| padstack | 159 | 159 | Unchanged Hellen merge noise |
| items_not_allowed | (n/a in g doc) | 199 | Keepout / local override tracks in module keepouts |
| silk_* | ~51 | 43 | Cosmetic |
| clearance | 28 | 12 | Improved vs g doc |

Top shorting leftovers (4): `/VR_OUT`↔empty M3 pad G; GND↔empty M1/M3 pad G. **Not** GND↔`/SGND` pairs in this K10 report.

## Must-list vs `docs/SPEC.md` (Boss brief)

| # | Item | Status after this pass |
|---|---|---|
| 1 | GND↔SGND shorts / AMPSEAL fanout | **Mostly cleared under K10 DRC** (0 GND↔SGND short pairs). Residual empty-net module-pad shorts + AMPSEAL fanout still need human copper eye before claiming clean. |
| 2 | J8 GND ↔ zone connectivity | **Fixed on PCB (rev i):** GND via @ `(114.9, 79.5)` + F.Cu tracks from J8 pads 5/6 (L-path on pad 6L to clear VBUS). J8 no longer in unconnected set. |
| 3 | SMBJ33A + UF flyback (+ 2×12 Ω) on INJ4/LS3 + bom_replace/LCSC | **BLOCKER — not fab-ready.** Sheets still text-only “flyback/TVS TBD”. Only **1×12 Ω gate** per channel on sch/PCB (`R1–R7`). No DO-214/SMA in `footprints/`; FET cluster packed. Do **not** fake parts. Needs layout pass (or SPEC change). |
| 4 | ANALOG + HALL conditioning | **Waived** — mega-module-only input lite written into `docs/SPEC.md` + this status. Frame stubs stay passthrough. |
| 5 | Q1–Q7 + gate Rs on JLC BOM with LCSC | **Done on `boards/microcore-i/` JLC BOM:** Q1–Q7=`C155647`, R1–R7=`C22783`. |
| 6 | Create Board after PCB change; bump revision | **BOARD_REVISION=i**; Create Board **green** → `boards/microcore-i/`. |

## Inventory

| Area | Present |
|---|---|
| Last green board package | `boards/microcore-i/` gerber/BOM/CPL/ibom/png/pdf |
| Pending | `boards/microcore-i/` after CI |
| Frame FETs Q1–Q7 + R1–R7 | On sch+PCB; LCSC via bom_replace (i) |
| Flyback/TVS | **Absent** |

## Decision hold (Boss)

Flyback/TVS layout vs SPEC defer is with Quintin via Boss — **do not start either path** until Boss confirms.

## Leftovers — **fab-ready** (must) — for Boss

1. **Add SMBJ33A + UF flyback per INJ/LS channel** (and second 12 Ω high-Z where SPEC requires) to schematic **and** PCB, with LCSC / `bom_replace` — or explicitly revise SPEC. **True layout blocker** (space + footprints).  
2. Human copper pass on residual **empty-net module pad G** shorts / AMPSEAL fanout (and confirm M2 S1 keepout unconnected is acceptable).  
3. ~~Confirm Create Board `boards/microcore-i/`~~ — **done** (green; Q/R on JLC BOM).

## Leftovers — nice-to-have

1. LCSC duplicate-partnumber warnings (100n / BAT54S).  
2. Silk cleanup.  
3. Title-block still says rev C in places.  
4. Diff-pair VR_P/VR_N noise.

## Quick safe fixes done this pass

- KiCad 10 DRC on current PCB; compared to rev-g status counts.  
- J8 GND via+track stitch (rev **i**).  
- `bom_replace_microcore-i.csv` LCSC for Q1–Q7 + R1–R7.  
- ANALOG/HALL mega-module-only waiver in SPEC.  
- README → microcore-i (last green); this status doc.  
- Kept incident note below.

**PCB content changed** → revision **i**.

## Incident: empty PCB on main (ce63db4)

Commit `ce63db4` (“Fix drill origin…”) **wiped** `microcore.kicad_pcb` to ~49 bytes (16063 lines → 1). Cause: an edit that replaced the whole file instead of only changing `aux_axis_origin` / `grid_origin`. Restored from `298ebd5` (rev h content) and set drill/place origin to Edge.Cuts bottom-left `(107.5, 148.0872)` (Hellen practice: Y grows downward → bottom-left = `(min_x, max_y)`). Guard: `bin/check-pcb-not-empty.sh` + Create Board job `guard-pcb-not-empty`.

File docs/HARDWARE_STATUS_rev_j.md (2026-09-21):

> **Superseded for current work:** see [HARDWARE_STATUS_rev_m.md](HARDWARE_STATUS_rev_m.md) (rev m: D1–D8 collector re-route).

# Micro Core hardware status — rev j

**Date:** 2026-09-21  
**Repo:** `quintinbannink42/micro-core`  
**KiCad basename:** `microcore` (`BOARD_PREFIX=micro`, `BOARD_SUFFIX=core`)  
**BOARD_REVISION:** **j** (fab-affecting: injector TVS + UF flyback + 2nd 12 Ω per INJ channel on sch+PCB)  
**Create Board artifacts:** last green `boards/microcore-h/`; `boards/microcore-i/` may appear from CI on `main`; **`boards/microcore-j/` after this rev is merged to `main`**.

## Verdict

Injector SPEC power-stage protection is now on schematic and PCB (real `DO214AC` footprints). **Not a fab order yet** until Create Board produces `boards/microcore-j/` and a human copper pass reviews the new alley / pocket-C parts against AMPSEAL keepout. Residual DRC is still expected Hellen keepout / empty-net module-pad merge (same class as rev i).

`microcore.kicad_pcb` remains substantial (~673 kB, 4 zones, 33 footprints). Drill origin unchanged: Edge.Cuts bottom-left `(107.5, 148.0872)`.

## What landed (rev j)

Per injector channel 1–4 (`INJ4.kicad_sch` + PCB):

| Ref | Function | Package | LCSC (`bom_replace_microcore-j.csv`) |
|---|---|---|---|
| R1–R4 | existing 12 Ω gate | R0603 | C22783 |
| R8–R11 | **2nd 12 Ω high-Z ballast** (FET drain → AMPSEAL `/INJn`) | R0603 | C22783 |
| D1–D4 | **US1M UF flyback** (anode `/INJn`, cathode `/V12_RAW`) | DO-214AC / SMA | C112545 |
| D5–D8 | **SMAJ33A** 33 V unidirectional TVS (cathode `/INJn`, anode GND) — DO-214 equivalent of SMBJ33A | DO-214AC / SMA | C143131 |

SMAJ33A is the SMA (DO-214AC) equivalent of SMBJ33A (SMB / DO-214AA), chosen so the FET cluster did not have to grow into the AMPSEAL courtyard. Electrical clamp is the same 33 V unidirectional TVS family.

LS3 (Q5–Q7) still has gate 12 Ω only. SPEC power-stage text is **4× injector** DPAK + TVS + UF + 2×12 Ω; LS flyback was not added.

### PCB placement (FET cluster not exploded)

Moving Q1–Q7 south/east would enter AMPSEAL courtyard (`J1` TE_776231 @ `(152.2, 129.99)`, silk ±38.45 × ±16.05 → north ~y=113.94) or the board edge. Cluster left in place; new parts use empty pockets:

- **R8–R11** at the SW corner of Q1–Q4; existing drain vias nudged off the DPAK tab so the ballast is the only drain↔`/INJ` link (`Net-(Qn-D)` vs `/INJn`).
- **D1–D4 (US1M)** in the power–MCU alley (~x=130, y=86.5–104.5), west of mega-mcu100, east of `power_12and5V` keepout.
- **D5–D8 (SMAJ33A)** in pocket C east of MCU / west of VR keepout (~x=170–175, y=76.8–80.2).
- `/V12_RAW` spine in the alley to the existing In2 via at `(111.4, 105.2)`.
- AMPSEAL keepout zones and F.Cu/B.Cu GND pour polygons were **not** rewritten (filled polygons unchanged). New tracks wrap **south of MCU** (~y=110.6–112.7), north of AMPSEAL.

Vendored footprint: `footprints/DO214AC.kicad_mod`.

## DRC leftovers (KiCad 10)

This environment has **no `kicad-cli`**. Last counted DRC was rev i (kicad-cli **10.0.6**): **425** total, mostly:

- padstack 159 (Hellen merge)
- items_not_allowed 199 (module keepout tracks)
- silk_* 43
- clearance 12
- shorting_items 4 (empty-net module pad G)
- unconnected_items 1 (F.Cu GND zone ↔ M2 pad S1 inside keepout)

**Expected new noise after rev j (not re-run here):**

- Courtyard tightness: SMA vs MCU east edge / VR west keepout; 0603 vs DPAK courtyards at Q1–Q4 SW corners.
- Extra `items_not_allowed` if any wrap track clips a module keepout.
- Zone fills are stale until KiCad refills F.Cu/B.Cu GND (Create Board / pcbnew fill). Thermal relief around new GND vias for D5–D8 should appear after refill.

Not claimed clean. Human copper eye still required on AMPSEAL fanout and empty-net module pad G shorts (rev i leftover).

## Create Board / fab path

Workflow: `.github/workflows/create-board.yaml`

1. `on: push` and `workflow_dispatch`
2. Job `guard-pcb-not-empty` runs `bin/check-pcb-not-empty.sh microcore.kicad_pcb`
3. Reuses `andreika-git/hellen-one/.github/workflows/create-board.yaml@master` (`hellen-one/kicad/bin/export.sh` → gerber/BOM/CPL/ibom under `boards/microcore-${BOARD_REVISION}/`)

**Exact next step for CI artifacts:** merge this branch to default **`main`** (or run **Actions → Create Board → Run workflow** on `main` after merge). Fab files are committed by that reusable workflow **on `main` only**. A PR-branch push may *run* the workflow but will not populate `boards/microcore-j/` on `main`.

`bom_replace_microcore-j.csv` is named for `BOARD_PREFIX`+`BOARD_SUFFIX`+`BOARD_REVISION` = `microcore-j`.

## Must-list vs `docs/SPEC.md`

| # | Item | Status |
|---|---|---|
| 1 | GND↔SGND / AMPSEAL fanout | Unchanged from rev i (K10: 0 GND↔SGND short pairs; empty-net pad G leftovers) |
| 2 | J8 GND stitch | Still present (rev i) |
| 3 | SMBJ33A + UF flyback + 2×12 Ω on INJ | **Done on sch+PCB** (SMAJ33A DO-214AC + US1M + R8–R11) |
| 4 | ANALOG + HALL | Still waived (mega-module-only) |
| 5 | Q1–Q7 + gate Rs LCSC | Still in bom_replace |
| 6 | Create Board after PCB change | **Needs `main` merge** → `boards/microcore-j/` |

## Leftovers — before ordering boards

1. Green Create Board `boards/microcore-j/` with D1–D8 / R8–R11 on JLC BOM.  
2. Human copper pass: pocket C TVS, alley UF, ballast at FET SW, AMPSEAL fanout.  
3. KiCad 10 DRC + zone refill.  
4. LS flyback/TVS only if product later requires it (not in SPEC 4-ch injector power-stage).

## Incident guard

Do not whole-file-replace `microcore.kicad_pcb`. Guard: `bin/check-pcb-not-empty.sh` (min 10 kB + `(zone` present). This pass only appended footprints/segments and retargeted existing INJ drain stubs/vias.

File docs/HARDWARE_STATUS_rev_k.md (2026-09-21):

> **Superseded for current work:** see [HARDWARE_STATUS_rev_m.md](HARDWARE_STATUS_rev_m.md) (rev m: D1–D8 collector re-route).

# Micro Core hardware status — rev k

**Date:** 2026-09-21  
**Repo:** `quintinbannink42/micro-core`  
**KiCad basename:** `microcore` (`BOARD_PREFIX=micro`, `BOARD_SUFFIX=core`)  
**BOARD_REVISION:** **k** (fab-affecting: D1–D8 flipped to B.Cu beside J1; frame SW_BOOT/SW_RESET removed)  
**Create Board artifacts:** last packages on main include `boards/microcore-j/`. **`boards/microcore-k/` after this rev is merged to `main`** (or Create Board on `main`). A PR-branch push may *run* Create Board but fab files land on `main` only.

## Verdict

Injector protection diodes are on the **bottom copper** next to the AMPSEAL, outside the TE_776231 silk/body keepout. Frame boot/reset buttons are gone from schematic and PCB (mega-mcu100 internal S100/S101 unchanged). **Not a fab order yet** until Create Board produces `boards/microcore-k/` and a human copper pass reviews B.Cu diode alley vs AMPSEAL pins / NPTH.

`microcore.kicad_pcb` remains substantial (zones present, 31 footprints after dropping two buttons). Drill origin unchanged: Edge.Cuts bottom-left `(107.5, 148.0872)`.

## What landed (rev k)

### 1. D1–D8 on B.Cu, nearer J1

| Ref | Function | Side | Placement |
|---|---|---|---|
| D1–D4 | US1M UF flyback (`/INJn` anode, `/V12_RAW` cathode) | **B.Cu** | West flank of J1, x=110.7, y=118.0–137.8, rot 90 |
| D5–D8 | SMAJ33A TVS (`/INJn` cathode, GND anode) | **B.Cu** | East flank of J1, x=194.0, y=118.0–137.8, rot 270 |

J1 TE_776231 @ `(152.2024, 129.9892)`, silk ±38.45 × ±16.05 → body box x=113.75–190.65, y=113.94–146.04. Diode courtyards stay **west of x=113.75** and **east of x=190.65**. Old F.Cu alley / pocket-C footprints and 0.4 mm wrap tracks to those pockets were removed. 1.5 mm FET→AMPSEAL injector fanout unchanged.

New B.Cu 0.5 mm collectors in the gap north of the INJ pin row stitch diode pads to J1 thru-hole pins; `/V12_RAW` west spine vias onto existing In2 at `(117.10, 124.90)`. GND vias sit beside D5–D8 anodes (B.Cu pour still needs KiCad refill).

### 2. Frame SW_BOOT / SW_RESET removed

Removed from `microcore.kicad_sch` and `microcore.kicad_pcb`, including silk and the frame-only BOOT0 / nReset / V33 / button-GND tracks and vias. MCU module pads `/BOOT0`, `/nReset`, `/V33` remain (internal mega buttons). `bom_replace_microcore-k.csv` has no SW_BOOT/SW_RESET rows.

## DRC leftovers (KiCad 10)

This environment has **no `kicad-cli`**. Last counted DRC was rev i (kicad-cli **10.0.6**): **425** total, mostly Hellen keepout / padstack / silk. Rev j/k add expected extra noise until zone refill:

- B.Cu SMD pads in the GND pour (thermals appear after fill)
- Courtyard tightness on the 6.25 mm west strip / 6.85 mm east strip beside AMPSEAL
- Residual empty-net module pad G shorts (rev i leftover)

Not claimed clean. Human copper eye still required on AMPSEAL fanout and the new B.Cu diode collectors vs NPTH / pin pads.

## Create Board / fab path

Workflow: `.github/workflows/create-board.yaml`

1. `on: push` and `workflow_dispatch`
2. Job `guard-pcb-not-empty` runs `bin/check-pcb-not-empty.sh microcore.kicad_pcb`
3. Reuses `andreika-git/hellen-one/.github/workflows/create-board.yaml@master`

**Exact next step for CI artifacts:** merge this branch to default **`main`**. Fab files are committed by that reusable workflow **on `main` only**. A PR-branch push may *run* the workflow but will not populate `boards/microcore-k/` on `main`.

`bom_replace_microcore-k.csv` is named for `BOARD_PREFIX`+`BOARD_SUFFIX`+`BOARD_REVISION` = `microcore-k`. ASCII-only comments (no ohm-symbol).

## Leftovers — before ordering boards

1. Green Create Board `boards/microcore-k/` with D1–D8 on bottom CPL / JLC BOM and no frame SW_BOOT/SW_RESET.  
2. Human copper pass: B.Cu diode flanks, collectors vs AMPSEAL NPTH, V12 spine, zone refill.  
3. KiCad 10 DRC + zone refill.  
4. LS flyback/TVS only if product later requires it.

## Incident guard

Do not whole-file-replace `microcore.kicad_pcb`. Guard: `bin/check-pcb-not-empty.sh` (min 10 kB + `(zone` present). Drill origin must stay Edge.Cuts bottom-left.

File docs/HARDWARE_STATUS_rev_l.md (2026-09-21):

> **Superseded for current work:** see [HARDWARE_STATUS_rev_m.md](HARDWARE_STATUS_rev_m.md) (rev m: D1–D8 collector re-route).

# Micro Core hardware status — rev l

**Date:** 2026-09-21  
**Repo:** `quintinbannink42/micro-core`  
**KiCad basename:** `microcore` (`BOARD_PREFIX=micro`, `BOARD_SUFFIX=core`)  
**BOARD_REVISION:** **l** (fab-affecting: refill F.Cu+B.Cu GND pours after rev-k diode move; Core EFI silkscreen)  
**Create Board artifacts:** last packages on main include `boards/microcore-j/`. **`boards/microcore-l/` after this rev is merged to `main`** (Create Board on a PR branch may run but fab files land on `main` only).

## Verdict

**Not production-ready.** GND pours are real filled copper on both outer layers, and Core EFI branding is on F.SilkS and B.SilkS. Do not order boards until a human copper pass fixes the rev-k B.Cu diode collectors (true shorts + unconnected diode pads) and Create Board produces `boards/microcore-l/`.

`microcore.kicad_pcb` remains substantial (~666 kB, 4 top-level zones, filled F.Cu+B.Cu GND). Drill origin unchanged: Edge.Cuts bottom-left `(107.5, 148.0872)`. D1–D8 stay on **B.Cu** beside J1, outside the AMPSEAL silk/body keepout.

## What landed (rev l)

### 1. F.Cu + B.Cu GND pours refilled

| Item | Value |
|---|---|
| Nets | **GND** only (not `/SGND`) |
| Layers | `F.Cu` and `B.Cu` (separate zones) |
| Outline | Edge.Cuts inset 0.4 mm: `(107.9, 71.9)`–`(197.1, 147.6872)` |
| Fill | `fill yes`; KiCad 10.0.6 `--refill-zones --save-board` |
| Clearance | `connect_pads` 0.2 mm |
| Thermal | `thermal_gap` 0.25 / `thermal_bridge_width` 0.3 |
| Islands | `island_removal_mode 0` (keep); F.Cu has a leftover island (see DRC) |

Filled-polygon bbox after refill matches the zone outline on both outer layers, including the west/east B.Cu diode flanks. AMPSEAL / module keepouts still forbid copperpour inside those courtyards.

`kicad-cli pcb drc` reports **0 GND ↔ `/SGND` short pairs**. Sensor ground stays a separate net.

### 2. Silkscreen branding (ASCII only)

Primary **F.SilkS** stack in the empty pocket east of mega-mcu100 / west of vr-max9924 / north of the FET cluster (`x=168.8`, `y=74.5–80.6`), plus the same strings on **B.SilkS** (`x=173.1`, mirrored). Avoids J1 courtyard, diode flanks, pads, and vias.

| String | Role |
|---|---|
| `Core EFI` | Brand |
| `Micro Core` | Model |
| `coreefi.co.za` | Company site |
| `microcore` | KiCad / fab basename |
| `coreefi_micro` | Firmware board id |
| `rev L` | Board revision |

All silk ≥ 0.8 mm (board min text height). Comments-layer note also says rev L.

## DRC summary (kicad-cli **10.0.6**)

Command: `kicad-cli pcb drc --format report --severity-all --units mm --refill-zones --output … microcore.kicad_pcb`

| Category | Count | Triage |
|---|---:|---|
| **Total violations** | **509** | 255 error / 254 warning |
| items_not_allowed | 199 | Hellen module keepout (M1 81 / M2 31 / M3 20 + other) — merge noise |
| padstack | 159 | Hellen merge noise |
| silk_over_copper | 65 | Mostly module silk clipped by mask/pads |
| **shorting_items** | **28** | **Must triage** — see below |
| silk_overlap | 20 | Cosmetic / module |
| solder_mask_bridge | 14 | Mostly B.Cu diode pad vs opposite-net stub |
| tracks_crossing | 7 | B.Cu INJ collectors overlapping each other |
| clearance | 6 | Includes B.Cu INJ vs AMPSEAL vias; FET cluster 0.05 mm |
| lib_footprint_issues | 5 | Vendored / Hellen |
| via_dangling | 4 | East INJ vias @ x=195.4 (D5–D8 alley) |
| copper_edge_clearance | 1 | Edge |
| holes_co_located | 1 | Merge |
| **unconnected_items** | **14** | 12 diode pad/track; 1 F.Cu island; 1 M2 S1 keepout |
| GND ↔ `/SGND` shorts | **0** | Pour did not bridge sensor ground |

### Shorts — real vs Hellen noise

**True / layout-blocking (rev k B.Cu diode collectors, not introduced by the pour):**

- SMA pads vs same-x 1.5 mm stubs: `/INJn` ↔ `/V12_RAW` on D1–D4, `/INJn` ↔ GND on D5–D8 (track lands on the opposite pad of the same diode).
- B.Cu INJ collectors vs AMPSEAL fanout vias: `/INJ3`↔`/HALL_CAM`, `/INJ3`↔`/IGN2`, `/INJ4`↔`/IGN4`, `/INJ4`↔`/IAT`, `/INJ1`↔`/DIN2`, `/INJ2`↔`/INJ3`.
- Related: `tracks_crossing` among B.Cu INJ spines; `via_dangling` on east INJ vias.

**Hellen-merge / empty-net (same class as rev i):**

- GND or `/VR_OUT` vs empty M1/M3 pad G (3 + 1).
- `/VR_N` vs Q1/Q3 drain tracks near VR keepout; Q4 pad vs R9 pad; `/INJ3`↔`/VR_OUT` on In1 (3).

**Keepout unconnected:** F.Cu GND zone ↔ M2 pad S1 (copperpour not allowed in module keepout) — treat as false positive unless copper review says otherwise. One F.Cu GND island remains (`island_removal_mode 0`).

## Create Board / fab path

Workflow: `.github/workflows/create-board.yaml`

1. `on: push` and `workflow_dispatch`
2. Job `guard-pcb-not-empty` runs `bin/check-pcb-not-empty.sh microcore.kicad_pcb`
3. Reuses `andreika-git/hellen-one/.github/workflows/create-board.yaml@master`

**Exact next step for CI artifacts:** merge this branch to default **`main`**. Fab files are committed by that reusable workflow **on `main` only**.

`bom_replace_microcore-l.csv` is named for `BOARD_PREFIX`+`BOARD_SUFFIX`+`BOARD_REVISION` = `microcore-l`. ASCII-only comments (no ohm-symbol). LCSC rows unchanged from rev k/j.

## Leftovers — before ordering boards

1. **Human copper pass on D1–D8 B.Cu placement** — collectors must not cross AMPSEAL NPTH/vias or the opposite SMA pad; diode pads must connect to their nets. This is a **true blocking leftover**.
2. Green Create Board `boards/microcore-l/` (CPL/JLC BOM with diodes on bottom).
3. Residual Hellen keepout / padstack / empty-net pad G noise (waive as merge artifact after the diode pass, or clean if copper review wants it).
4. LS channels still lack flyback/TVS (SPEC was injector-focused; not closed this pass).
5. ANALOG/HALL frame stubs remain mega-module-only (already waived in SPEC).

## Incident guard

Do not whole-file-replace `microcore.kicad_pcb`. Guard: `bin/check-pcb-not-empty.sh` (min 10 kB + `(zone` present). Drill origin must stay Edge.Cuts bottom-left `(107.5, 148.0872)`.

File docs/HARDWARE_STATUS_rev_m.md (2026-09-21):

# Micro Core hardware status — rev m

**Date:** 2026-09-21  
**Repo:** `quintinbannink42/micro-core`  
**KiCad basename:** `microcore` (`BOARD_PREFIX=micro`, `BOARD_SUFFIX=core`)  
**BOARD_REVISION:** **m** (fab-affecting: re-route D1–D8 collectors; refill F.Cu+B.Cu GND pours)  
**Create Board artifacts:** last packages on main include `boards/microcore-j/`. **`boards/microcore-m/` after this rev is merged to `main`** (Create Board on a PR branch may run but fab files land on `main` only).

## Verdict

**Not production-ready.** The rev-k B.Cu diode-collector shorts and unconnected SMA pads are closed. Do not order boards until Create Board produces `boards/microcore-m/` and a human reviews remaining Hellen-merge DRC (keepout / padstack / leftover In1 `/INJ3`↔`/VR_OUT`).

`microcore.kicad_pcb` remains substantial (~686 kB, filled F.Cu+B.Cu GND zones). Drill origin unchanged: Edge.Cuts bottom-left `(107.5, 148.0872)`. D1–D8 stay on **B.Cu** beside J1, outside the AMPSEAL silk/body keepout.

## What landed (rev m)

### 1. D1–D8 collectors (human copper pass)

Rev-k 0.5 mm B.Cu east–west spines at y≈121.65–124.05 (through AMPSEAL fanout) and 1.5 mm stubs on the wrong SMA pad (B.Cu X-mirror) are **deleted**.

Replacement (B.Cu pad stubs + F–B vias at diode bodies; buses south of J1 where all layers were empty):

| Net | West / east | Around J1 | Join |
|---|---|---|---|
| `/V12_RAW` | B.Cu spine x=108.40 on **true cathode Y** 120.05/126.65/133.25/139.85 | — | existing via `(109.3, 124.9)` |
| GND (D5–D8) | B.Cu stubs x=194→195.10 on anode Y | — | B.Cu GND pour |
| `/INJ1` | vias `(110.7, 118)` / `(194, 118)` | In1 south y=146.55; In2 at y=118 | via `(166.0, 112.3)` |
| `/INJ2` | vias `(110.7, 123.15)` / `(194, 124.6)` | In1 south y=147.25; B.Cu y=114.9 | existing B.Cu 1.5 mm `(165.3, 114.9)` |
| `/INJ3` | vias `(110.7, 131.2)` / `(194, 131.2)` | In2 south y=146.55, peel x=191.50 | existing In2 1.5 mm `(162.0, 122.7)` |
| `/INJ4` | vias `(110.7, 137.8)` / `(194, 137.8)` | In2 south y=147.25, peel x=196.40; westbound y=120.80 | via `(162.8, 112.3)` |

INJ pad Y after B.Cu X-mirror: 115.95 / 122.55 / 129.15 / 135.75. Two nets per inner layer on the south strip so buses stay parallel and do not T-cross. D1–D4 remain x=110.7 rot 90; D5–D8 x=194 rot −90.

F.Cu+B.Cu GND zones refilled after the copper edit (`kicad-cli --refill-zones --save-board`).

### 2. Silkscreen / title (ASCII, preserved from rev l with letter bump)

Primary **F.SilkS** at `x=168.8`, `y=74.5–80.6`; **B.SilkS** at `x=173.1`. Strings: `Core EFI`, `Micro Core`, `coreefi.co.za`, `microcore`, `coreefi_micro`, **`rev M`**. Title block rev **M**.

## DRC summary (kicad-cli **10.0.6**)

Command: `kicad-cli pcb drc --format json --severity-all --units mm --refill-zones --save-board`

| Category | Count | Triage |
|---|---:|---|
| **Total violations** | **469** | 219 error / 250 warning |
| items_not_allowed | 199 | Hellen module keepout (M1/M2/M3) — merge noise |
| padstack | 159 | Hellen merge noise |
| silk_over_copper | 65 | Mostly module silk; diode silk vs copper |
| silk_overlap | 20 | Cosmetic / module |
| **shorting_items** | **12** | **0 new diode-collector shorts** — see below |
| clearance | 5 | FET cluster / merge; not D1–D8 collectors |
| lib_footprint_issues | 5 | Vendored / Hellen |
| solder_mask_bridge | 2 | Q4/R9 front; M3 pad G / `/V5_REF` rear — not diodes |
| copper_edge_clearance | 1 | Edge |
| holes_co_located | 1 | Duplicate `/INJ1` via @ `(174.2, 90.35)` (Hellen leftover) |
| **unconnected_items** | **2** | M2 S1 keepout; F.Cu GND island. **0 diode pads** |
| GND ↔ `/SGND` shorts | **0** | Pour did not bridge sensor ground |
| tracks_crossing | **0** | Was 7 on rev l |
| via_dangling | **0** | Was 4 east INJ vias on rev l |

### Shorts — real vs Hellen noise

**Closed this pass (rev-k collectors):**

- SMA pads vs same-x 1.5 mm stubs: `/INJn`↔`/V12_RAW` (D1–D4), `/INJn`↔GND (D5–D8).
- B.Cu INJ collectors vs AMPSEAL fanout vias: `/INJ3`↔`/HALL_CAM`/`/IGN2`, `/INJ4`↔`/IGN4`/`/IAT`, `/INJ1`↔`/DIN2`, `/INJ2`↔`/INJ3`.
- Diode pad unconnected / solder-mask bridge on D1–D8 / dangling east INJ vias.

**Still present (not introduced by this pass):**

- `/INJ3`↔`/VR_OUT` on **In1** near `(174.2, 98.4)` / `(174.3, 104.0)` — Hellen leftover 1.5 mm fanout vs VR. Out of this B.Cu diode pass.
- GND or `/VR_OUT` vs empty M1/M3 pad G; `/VR_N` vs Q1/Q3 drain tracks; Q4 pad vs R9 pad.

**Keepout unconnected:** F.Cu GND zone ↔ M2 pad S1 (copperpour not allowed in module keepout). One F.Cu GND island remains (`island_removal_mode 0`).

## Create Board / fab path

Workflow: `.github/workflows/create-board.yaml`

1. `on: push` and `workflow_dispatch`
2. Job `guard-pcb-not-empty` runs `bin/check-pcb-not-empty.sh microcore.kicad_pcb`
3. Reuses `andreika-git/hellen-one/.github/workflows/create-board.yaml@master`

**Exact next step for CI artifacts:** merge this branch to default **`main`**. Fab files are committed by that reusable workflow **on `main` only**.

`bom_replace_microcore-m.csv` is named for `BOARD_PREFIX`+`BOARD_SUFFIX`+`BOARD_REVISION` = `microcore-m`. ASCII-only comments (no ohm-symbol). LCSC rows unchanged from rev k/j.

## Leftovers — before ordering boards

1. Green Create Board `boards/microcore-m/` (CPL/JLC BOM with diodes on bottom).
2. Residual Hellen keepout / padstack / empty-net pad G noise (waive as merge artifact, or clean if copper review wants it).
3. Preexisting In1 `/INJ3`↔`/VR_OUT` near the VR module (not part of the D1–D8 alley).
4. LS channels still lack flyback/TVS (SPEC was injector-focused; not closed this pass).
5. ANALOG/HALL frame stubs remain mega-module-only (already waived in SPEC).

## Incident guard

Do not whole-file-replace `microcore.kicad_pcb`. Guard: `bin/check-pcb-not-empty.sh` (min 10 kB + `(zone` present). Drill origin must stay Edge.Cuts bottom-left `(107.5, 148.0872)`.

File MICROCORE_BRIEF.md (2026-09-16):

# Micro Core — Boss brief (locked)

**Product:** Micro Core (Core EFI Hellen-One rusEFI ECU)  
**Repo:** `/workspace/micro-core` (GitHub main)  
**Owner (orchestration):** Boss  
**Assigned agent:** Researcher  
**Separate from:** PowerCore (Jeoff / Code Jeoff) — do not mix streams  

**Locked:** 2026-09-16 (Quintin)

## Mission

Finish Micro Core **hardware**, then **start firmware compilation** for board `coreefi_micro`.

## What it is

- Microsquirt-class sealed-box 4-cyl sequential wire-in ECU  
- Hellen-One / STM32F4, 35-way AMPSEAL **vertical** header (TE 776231-1 / plug 776164-1)  
- KiCad basename `microcore`, rev **g** (`BOARD_PREFIX=micro`, `BOARD_SUFFIX=core`)  
- Firmware board name: `coreefi_micro`  
- Spec: `docs/SPEC.md`

## Current state (as of Boss review)

- Hardware repo on `main` with rev g GND pours, AMPSEAL keepout work, Create Board outputs under `boards/microcore-g/`, gerbers present  
- README still says “spec freeze in progress”  
- **No firmware overlay repo found yet** under `/workspace` — firmware still to bootstrap for `coreefi_micro`  
- Do not confuse with PowerCore / hellen-pdm-razor

## Priorities for Researcher

1. **Hardware finish** — audit open copper/DRC/BOM/CI Create Board health on rev g; close remaining gaps to fab-ready; report concrete leftover list + DRC.  
2. **Firmware start** — bootstrap rusEFI custom board / overlay for `coreefi_micro` matching Micro Core pinout/spec; get a **green compile** (first flashable image).  
3. Keep reports to Boss; do not pull Jeoff or Code Jeoff unless Boss asks.

## Out of scope for this track

PowerCore PDM work, hellen-pdm-razor, TunerStudio PDM INI.

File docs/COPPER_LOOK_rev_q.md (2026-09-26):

# Copper look — rev q

**Date:** 2026-09-26
**Board:** `microcore.kicad_pcb`
**Tip:** `1881d92a4f4177e305fe7676f20a1317a34590b1` (rev Q title block, after PR #13)
**Drill origin:** `(aux_axis_origin 107.5 148.0872)`
**Scope:** gate-driver copper (U1–U4, C1–C8, R1–R7, Q1–Q7 gates) and the GND stitch at `(131.3, 82)`. Hellen M1/M2/M3 were not edited and were not re-routed.

## Verdict

**PASS with notes.** No frame short or unconnected driver net showed up in this look. Leftover #3 in `docs/HARDWARE_STATUS_rev_q.md` can be cleared after Quintin eyeballs the pours listed at the bottom.

This review does not order boards. Create Board, the JLC BOM, and a look at the B.Cu pours in KiCad are still required before an order.

## How this was checked

The board file at the tip above was parsed directly: footprints, pad nets, tracks, vias, keepout rectangles, and the stored GND fills.

Pad centers use KiCad's Y-down rotation. Two centers were checked against the rev q interactive BOM (`boards/microcore-q`, generated at `da9c606`, before the stitch via): C1 pin 1 and R7 pin 1. Later commits on this tip are the stitch via, a duplicate `/INJ1` via removal, and silk. Driver copper is the same file the BOM was plotted from, plus that stitch.

`kicad-cli` is not in this environment, so DRC was not re-run. The counts below are the ones `docs/HARDWARE_STATUS_rev_q.md` records for this same tip. This look did not change the board, so those counts still belong to this file.

Default netclass clearance in `microcore.kicad_pro` is 0.1 mm. GND zone `connect_pads` clearance is 0.2 mm. Distances below were measured edge to edge on the stored geometry (track width and via diameter included). Roundrect pad corners were modeled as full rectangles, so pad-to-pour numbers from that model are not used as pass/fail.

## Checklist

| Item | Result | Note |
|---|---|---|
| U1–U4 placement and nets | Pass | All four SLM27524CA-DG, LCSC C2921387, `microcore-fp:SOIC-8`, layer B.Cu. Pin map matches the rev q status table. |
| ENA / ENB / VDD on `/V12_RAW` | Pass | U1–U4 pins 1, 6, and 8. One track/via island with the bypass caps, D1–D4, D9–D11, J1 pin 1, and M2 V3. |
| Driver GND | Pass | Pin 3 on U1–U4 is `GND`. U4 pin 2 (INA) is also `GND`. |
| U4 channel A | Pass | INA tied to `GND`. OUTA net is `unconnected-(U4-OUTA-Pad7)` with zero tracks. |
| Bypass C1–C8 | Pass | B.Cu. C1/C3/C5/C7 are 100 nF C14663. C2/C4/C6/C8 are 1 uF C559769. Each has one GND pad and one `/V12_RAW` pad, and the V12 pads sit on the same island as the drivers. |
| Gate path R1–R7 to Q1–Q7 | Pass | Each used OUT net is its own island: driver OUT pad, tracks, one resistor pad. Each gate net is its own island: the other resistor pad to the DPAK gate. MCU nets are not on those pads. |
| MCU net vs driver OUT copper | Pass | No shared copper. Closest measured gap is 0.134 mm (see notes). |
| `/V12_RAW` spine and stitches | Pass | B.Cu spine at x = 167.75. Stitch via at `(158.6, 113.0)`. U4 VDD uses the F.Cu hop. |
| R6 / U3 OUTA detour | Pass | Leaves B.Cu west of Q3, crosses on In1.Cu, returns to F.Cu at R6. No overlap with `/VR_N`. |
| Island stitch `(131.3, 82)` | Pass | GND, 0.8 / 0.4, F.Cu–B.Cu. Inside the small F.Cu GND island and the main B.Cu GND pour. Outside M1, M2, and M3 keepouts. No foreign-net fill hit. |
| DRC electrical on frame nets | Attention | Not re-run here. Recorded for this tip: 399 violations (207 error / 192 warning), 1 unconnected (M2 pad S1), `silk_overlap` 0. Recorded `shorting_items` are the four Hellen pad-G pairs. This look found 0 overlaps among the driver nets, `/V12_RAW`, `/VR_N`, and the GND fills. |

## Driver map (measured)

SLM27524 pinout used: 1 ENA, 2 INA, 3 GND, 4 INB, 5 OUTB, 6 VDD, 7 OUTA, 8 ENB.

| Ref | At (mm) | Channel | MCU pad | OUT pad | Resistor | FET gate |
|---|---|---|---|---|---|---|
| U1 | (171.5, 84.2) | B | pin 4 `/OUT_INJ1` (M1 E17) | pin 5 `Net-(U1-OUTB)` | R1 | Q1 |
| U1 | | A | pin 2 `/OUT_INJ2` (M1 E16) | pin 7 `Net-(U1-OUTA)` | R2 | Q2 |
| U2 | (173.4, 90.0) | B | pin 4 `/OUT_INJ3` (M1 E15) | pin 5 `Net-(U2-OUTB)` | R3 | Q3 |
| U2 | | A | pin 2 `/OUT_INJ4` (M1 E14) | pin 7 `Net-(U2-OUTA)` | R4 | Q4 |
| U3 | (173.8, 96.1) | B | pin 4 `/OUT_LS1` (M1 E18) | pin 5 `Net-(U3-OUTB)` | R5 | Q5 |
| U3 | | A | pin 2 `/OUT_LS2` (M1 E19) | pin 7 `Net-(U3-OUTA)` | R6 | Q6 |
| U4 | (184.0, 106.0) | B | pin 4 `/OUT_LS3` (M1 E20) | pin 5 `Net-(U4-OUTB)` | R7 | Q7 |
| U4 | | A | pin 2 `GND` | pin 7 no track | — | — |

R1–R7 are 12 ohm on F.Cu. Q1–Q7 are NCE4080K on F.Cu, gate on pad 1. Local caps sit east of each driver: C1+C2 at U1, C3+C4 at U2, C5+C6 at U3, C7+C8 at U4.

MCU copper for `/OUT_INJ1`–`/OUT_INJ4` and `/OUT_LS1`–`/OUT_LS3` joins the M1 edge pad to the driver input (inner layer, one via, short B.Cu into the pin). It does not land on R1–R7 or on a FET gate. The old through-vias that used to sit on those resistors are gone (no co-located via pair anywhere on the board).

## `/V12_RAW` spine, hop, and the south stitch

- Existing B.Cu rail includes the segment `(154.8, 110.4)` → `(167.75, 110.4)`.
- Spine is the B.Cu track at x = 167.75 from y = 110.4 up to y = 83.5, with taps to U1–U3 and the nearby caps.
- U4 VDD does not stay on that spine. A via at `(168.8, 88.4)` takes `/V12_RAW` to F.Cu, runs `(168.8, 83.2)` → `(182.4, 83.2)` → `(182.4, 104.0)` → `(184.5, 104.0)`, then a via back to B.Cu and into U4 pin 6 at `(186.475, 105.365)`. Enables are the same net on the chip.
- In the window x = 165–190, y = 80–112, the closest foreign F.Cu copper to that hop is `/OUT_INJ1` at 0.150 mm. Next is Q1 drain copper at 0.250 mm. Both are above the 0.1 mm default clearance.
- Stitch via `(158.6, 113.0)`, uuid `9e514094-7125-4cbe-82d1-8ea222a04ee1`, 0.8 / 0.4, F.Cu–B.Cu, net `GND`. The via center is inside the main F.Cu GND fill and inside a B.Cu GND polygon of about 33.9 mm2 (the pocket south of the spine).

Reviewed tracks in the driver window (x roughly 150–200) stay at least 0.200 mm off the stored GND fill. The minimum hits that 0.200 mm value on several `/V12_RAW`, gate, and OUT segments, which matches the zone clearance parameter.

## R6

`Net-(U3-OUTA)` path:

1. B.Cu from U3 pin 7 `(176.275, 96.735)` to `(174.8, 96.735)` to `(174.8, 97.1)`.
2. Via `(174.8, 97.1)`.
3. In1.Cu `(174.8, 97.1)` → `(180.0, 97.1)` → `(180.0, 101.2)` → `(183.3, 101.2)`.
4. Via `(183.3, 101.2)`, then F.Cu into R6 pad 2 at `(184.7, 101.2)`.

x = 174.8 is west of the Q3 drain tab. The In1 run at y = 97.1 is north of the `/VR_N` via at `(178.3, 98.5)`. `/VR_N` is one island (J1 pin 29, M3 W1, vias at `(178.3, 119.2)`, `(178.3, 98.5)`, `(179.1, 90.0)`) and does not overlap this net. R6 pad 1 continues on F.Cu to Q6 gate.

## Island stitch `(131.3, 82)`

| | |
|---|---|
| Via | One via, uuid `a7c3e1d4-6b28-4f05-9c71-2e8d4b6a91f0` |
| At | `(131.3, 82.0)` |
| Size / drill | 0.8 / 0.4 |
| Layers | F.Cu – B.Cu |
| Net | `GND` |

- F.Cu: via center is inside the small GND fill, area 27.14 mm2, bbox `(129.115, 74.541)`–`(133.681, 87.157)`. That is the island west of the M1 keepout.
- B.Cu: via center is inside the main GND pour.
- In1.Cu and In2.Cu: no GND fill covers the point, and no foreign fill covers the via disk.
- Keepouts (same rectangle copied at board level and inside the module): M2 `(109.750, 82.200)`–`(126.550, 102.790)`, M1 `(133.681, 74.126)`–`(167.481, 109.926)`, M3 `(178.768, 72.840)`–`(193.668, 82.240)`. The via disk is outside all three. Gap from the via copper to the M1 keepout edge is 1.981 mm. Gap to the M2 keepout edge is 4.355 mm.
- Nearest foreign copper, measured from the 0.8 mm via disk: `/VIGN_SENSE` F.Cu track `(128.3, 81.85)`–`(132.4, 85.95)` at 1.465 mm. Next is `/VBAT` F.Cu at 1.501 mm. No foreign pad or track intersects the via.

## DRC electrical (this tip, not re-run)

From `docs/HARDWARE_STATUS_rev_q.md` for `1881d92`:

| Counter | Value |
|---|---|
| Violations | 399 (207 error / 192 warning) |
| Unconnected | 1 (M2 pad S1 vs F.Cu GND) |
| `shorting_items` | 4 (Hellen pad-G pairs) |
| `clearance` | 2 (Hellen M3) |
| `silk_overlap` | 0 |
| `tracks_crossing` | 0 |

Owner table: `docs/DRC_TRIAGE_rev_q.md`. Nothing in that error set is a frame driver net. This look's overlap pass (driver nets, `/V12_RAW`, `/VR_N`, GND fills, same layer) found 0 intersecting pairs.

## What Quintin should still eyeball in KiCad

These are visual checks. The geometry pass did not flag them as shorts.

1. B.Cu pours around U1–U4. Several OUT nets are stair-stepped in 0.2 mm jogs (U1 OUTA/OUTB, U2 OUTB, U3 OUTB, U4 OUTB). Confirm the GND pour still has a real neck around those stairs and around the x = 167.75 spine.
2. West side of U1 on B.Cu. `/OUT_INJ2` and `Net-(U1-OUTB)` come within 0.134 mm near `(171.53, 85.52)` to `(171.66, 85.56)`. Their through-via copper is 0.143 mm apart near `(170.91, 85.75)` to `(170.82, 85.87)`. Default clearance is 0.1 mm.
3. U3 input via `(173.25, 95.5)` vs the `Net-(U3-OUTB)` B.Cu stair. Gap measured 0.152 mm at x = 173.25, y about 95.90 to 96.05.
4. F.Cu `/V12_RAW` hop from `(168.8, 83.2)` to `(184.5, 104.0)`, especially the vertical at x = 182.4 between the two DPAK columns, and the 0.150 mm approach to `/OUT_INJ1`.
5. R6 on In1.Cu at y = 97.1 where it passes the Q3 drain (F.Cu) and the `/VR_N` via at `(178.3, 98.5)`.
6. R7, vertical on F.Cu at x = 184.16. Gate net and OUT net are 0.145 mm apart, which is the resistor gap. Confirm the stair from U4 does not nick the gate track.
7. U4 pin 7, the floating OUTA pad at `(186.475, 106.635)` on B.Cu. It has no track. Confirm the B.Cu GND pour is pulled back from that pad and from the other SOIC pads (the pour is close; a rectangle model of the roundrect is not a reliable clearance).
8. Stitch `(131.3, 82)` on the F.Cu island edge, and stitch `(158.6, 113.0)` in the B.Cu pocket south of the spine. Keepout edges are clear on the numbers above; the pour outline is the part to see.

## Order

No fab order from this review alone. The board file was not modified.

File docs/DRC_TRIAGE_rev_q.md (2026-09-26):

# DRC triage — rev q

**Date:** 2026-09-26
**Board:** `microcore.kicad_pcb` on `main` at `da9c606` (Create Board `boards/microcore-q/` already landed), plus one frame via.
**Checker:** `kicad-cli` 10.0.6

```
kicad-cli pcb drc --format json --severity-all --units mm --schematic-parity
```

`kicad-cli` prints three separate counters. The 473 violations are not the sum of the other two.

| Counter | Before | After | Delta |
|---|---:|---:|---:|
| Violations | 473 (207 error / 266 warning) | 473 (207 error / 266 warning) | 0 |
| Unconnected items | 2 | 1 | -1 |
| Schematic parity | 222 | 222 | 0 |

Every violation category count is unchanged. The only delta is the floating F.Cu GND island, which was an unconnected item, not one of the 473.

Drill origin is still `(aux_axis_origin 107.5 148.0872)`. Hellen modules M1/M2/M3 were not edited. No fab pack in this change.

## Triage

| Category | Count | Owner | Action |
|---|---:|---|---|
| `items_not_allowed` module pads | 132 | Hellen module. M1 81, M2 31, M3 20. Pads sit in the module keepout. | ignore |
| `items_not_allowed` tracks | 67 | Frame tracks clipped by the M1/M2/M3 keepouts (some hits are counted twice because a board-level keepout copies the module keepout). Includes the shortened `/OUT_INJ1` segment from rev q. | ignore |
| `padstack` | 159 | Hellen module. M2 111, M1 32, M3 16. | ignore |
| `silk_over_copper` | 53 | Frame silk on Q/R/D, including the D9–D14 back silk noted on rev p. | done (follow-up) |
| `silk_over_copper` | 28 | Hellen M2. | later / ignore |
| `silk_overlap` | 19 | Frame reference silk (injector FETs, ballast resistors, LS FETs). | done (follow-up) |
| `silk_overlap` | 1 | Q2 reference vs Hellen M3 silk. | done |
| `lib_footprint_issues` | 5 | Tooling. See below. | ignore |
| `shorting_items` | 4 | Hellen pad G vs an empty-net pad, or vs one frame track. Exact pairs below. | ignore |
| `clearance` | 2 | Hellen M3. PTH E4 `/V5_REF` vs empty pad G on B.Cu and In1.Cu. | ignore |
| `solder_mask_bridge` | 1 | Hellen M3. Same E4 vs pad G pair, rear mask. | ignore |
| `copper_edge_clearance` | 1 | Hellen M3 pad G on In2.Cu touches Edge.Cuts. | ignore |
| `holes_co_located` | 1 | Frame. Two identical `/INJ1` vias. | done (follow-up) |
| Unconnected, M2 pad S1 | 1 | Hellen module. Pad is inside the M2 keepout, so the pour cannot reach it. | ignore |
| Unconnected, F.Cu GND island | 1 | Frame pour west of the M1 keepout. | fix-now (done) |
| Schematic `net_conflict` | 175 | Hellen module. All 175 name M1, M2, or M3. None name a frame ref (Q, U, R, D, C, J). | ignore |
| Schematic `footprint_symbol_mismatch` | 32 | Frame library-id string. Embedded name is `DPAK` / `R0603` / `DO214AC`; the symbol says `microcore-fp:...`. Same land. D1–D14, Q1–Q7, R1–R11. | left (see follow-up) |
| Schematic `footprint_symbol_field_mismatch` | 15 | Cosmetic. J8 datasheet `~` vs empty; M1/M2 description; LCSC field missing on D1–D8 and R8–R11. BOM is `bom_replace_microcore-q.csv`. | ignore |

132 + 67 + 159 + 53 + 28 + 19 + 1 + 5 + 4 + 2 + 1 + 1 + 1 = 473.

## Frame fix

One unconnected item was frame copper. The F.Cu GND fill had a 27.1 mm² island, bbox `(129.12, 74.54)`–`(133.68, 87.16)`. It sits west of the M1 keepout (keepout starts at x = 133.68119) and east of the M2 keepout (ends at x = 126.55). Nothing on that island was a stitch. B.Cu under it is the main GND pour.

Stitch via, same size as the other GND stitches:

| | |
|---|---|
| At | `(131.3, 82)` |
| Size / drill | 0.8 / 0.4 |
| Layers | F.Cu – B.Cu |
| Net | `GND` |

Nearest foreign copper is about 1.4 mm (`/VBAT`, `/VIGN_SENSE`, M1 pad G). The via is outside all three module keepouts. Both pours already covered that point, so the stored fill did not need a rewrite. After the via, unconnected items are 1. Violation counts stayed 473. No new short, clearance, keepout, or parity item.

## Hellen electrical noise (do not edit M1/M2/M3)

These are the same pairs `docs/HARDWARE_STATUS_rev_q.md` inherited from rev p. No project net or label on a frame part is wrong. The empty pad is `<no net>` copper inside the module.

**Shorts**

| Pair | Where |
|---|---|
| M3 pad G `<no net>` on F.Cu `(186.175, 82.265)` | Frame track `/VR_OUT` on F.Cu, length 2.6163 mm, start `(184.15, 83.622)` |
| M3 pad G `GND` `(178.725, 75.84)` | M3 pad G `<no net>` `(185.925, 72.64)`, both F.Cu |
| M1 pad G `GND` `(133.28119, 76.67602)` | M1 pad G `<no net>` `(133.28119, 79.72601)`, both F.Cu |
| M1 pad G `GND` `(133.28119, 76.67602)` | M1 pad G `<no net>` `(137.18119, 74.12602)`, both F.Cu |

**Clearance and mask (one pad pair, three reports)**

M3 PTH pad E4 `/V5_REF` `(193.425, 73.04)` against M3 pad G `<no net>` `(186.025, 72.7775)` on B.Cu and on In1.Cu. Actual clearance 0 mm, rule 0.1 mm. The B.Cu pair is also the rear solder-mask bridge.

**Edge**

M3 pad G `<no net>` on In2.Cu `(185.7875, 72.74)` touches the Edge.Cuts rectangle `(107.5, 71.5)`–`(197.5, 148.0872)`. Rule 0.2 mm, actual 0.

**Unconnected left in place**

M2 pad S1 `GND` `(109.850001, 87.15)` vs the F.Cu GND zone. The pad is inside the M2 keepout `(109.75, 82.2)`–`(126.55, 102.79)`. A via there would be another `items_not_allowed`.

**`lib_footprint_issues`**

| Ref | Report |
|---|---|
| M1 | Library `hellen-one-mega-mcu100-0.3` is not enabled in this KiCad config |
| M2 | Library `hellen-one-power_12and5V-0.3` is not enabled |
| M3 | Library `hellen-one-vr-max9924-0.3` is not enabled |
| J8 | Library `hellen-one-common` is not enabled |
| J1 | Footprint `TE_776231` not found in `kicad6-libraries` |

Create Board already produced `boards/microcore-q/` with this J1. Do not retarget the AMPSEAL footprint from this warning.

**Duplicate via**

Two board-level vias, both `/INJ1`, both `(174.2, 90.35)`, size 0.8, drill 0.4. UUIDs `7e5055f5-3e87-43d5-ba01-377e73eca3d2` and `bb928a49-411f-561d-bb74-63aa78d8f3f6`. Same net, so this was one extra drill mark, not a short. The follow-up below removed `bb928a49-411f-561d-bb74-63aa78d8f3f6` and kept `7e5055f5-3e87-43d5-ba01-377e73eca3d2`.

## What still blocks a fab order

Nothing beyond Hellen noise and a human copper review.

`boards/microcore-q/` is already on `main`. This pass did not add a short, a clearance error, or a frame unconnected item. The remaining DRC errors are module keepout hits, the four pad-G shorts, the M3 E4 clearance/mask pair, the M3 edge hit, and M2 pad S1. Frame silk warnings (including the Q2 vs M3 overlap) and the duplicate `/INJ1` via are cleared in the follow-ups below. M2 silk stays later / ignore. Library-id parity warnings remain. A person should still look at the rev q gate-driver copper and at this stitch before ordering.

## Frame silk and duplicate via

Follow-up on the frame rows above. Hellen M1/M2/M3 were not edited. Drill origin is still `(107.5, 148.0872)`. No fab pack. Same checker as the table above.

| Category | Before | After | Delta |
|---|---:|---:|---:|
| Violations | 473 (207 error / 266 warning) | 400 (207 error / 193 warning) | -73 |
| `silk_over_copper` | 81 | 28 | -53 (frame Q/R/D, including D9–D14 back silk) |
| `silk_overlap` | 20 | 1 | -19 (frame reference silk) |
| `holes_co_located` | 1 | 0 | -1 |
| Unconnected items | 1 | 1 | 0 |
| Schematic parity | 222 | 222 | 0 |

Errors stayed 207. `items_not_allowed`, `padstack`, `shorting_items`, `clearance`, the M3 mask/edge pair, and M2 pad S1 did not move. After that pass one `silk_overlap` remained: Q2's reference against M3 silk. The 28 `silk_over_copper` hits are all M2 and stay later / ignore.

The extra `/INJ1` via `bb928a49-411f-561d-bb74-63aa78d8f3f6` is gone. The via kept at `(174.2, 90.35)` is `7e5055f5-3e87-43d5-ba01-377e73eca3d2` (0.8 / 0.4, F.Cu–B.Cu).

Silk edits are on the frame footprints only. Reference text for Q3–Q6 and R8–R11 moved off the pad or the neighboring outline. Q/R/D outline silk, including the D9–D14 back silk, was shortened or dropped where it crossed a pad or another frame outline. Parts still have silk. M2 graphics were not moved. The Q2 reference was still on the M3 silk after this pass; the next section moves it.

`footprint_symbol_mismatch` (32) was left. Writing `microcore-fp:DPAK` / `R0603` / `DO214AC` on the embedded footprint clears that parity warning, then KiCad diffs the copy against `footprints/*.kicad_mod` and adds `lib_footprint_mismatch` (19 on the untouched board, more after these silk trims). The lands were not redrawn to force that match.

## Q2 reference vs M3

The last `silk_overlap` was Q2's reference at `(190.6, 82.0)` against M3's south F.SilkS segment (`6ade2831-95f2-41d0-b254-0a71b67e8e91`). Only that reference was unlocked and moved to relative `(1.1, -5.1)`, board `(190.6, 81.4)`. M3 graphics were not edited. Hellen M1/M2/M3 were not edited. Drill origin is still `(107.5, 148.0872)`. No fab pack.

| Category | Before | After | Delta |
|---|---:|---:|---|
| Violations | 400 (207 error / 193 warning) | 399 (207 error / 192 warning) | -1 |
| `silk_overlap` | 1 | 0 | -1 |
| `silk_over_copper` | 28 | 28 | 0 (all M2, later / ignore) |
| Unconnected items | 1 | 1 | 0 (M2 pad S1) |
| Schematic parity | 222 | 222 | 0 |

Errors stayed 207. `items_not_allowed`, `padstack`, `shorting_items`, `clearance`, the M3 mask/edge pair, and M2 pad S1 did not move.

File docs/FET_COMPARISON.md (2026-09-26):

# DPAK FET comparison — 3.3 V gate, rev o land

**Date:** 2026-09-24  
**Repo:** `quintinbannink42/micro-core`  
**Board:** rev o, Q1–Q7 on `microcore-fp:DPAK` (`footprints/DPAK.kicad_mod`)  
**Written against rev o.** It compared parts and recommended keeping NCE4080K. It did not edit the BOM.

**Quintin override (2026-09-25):** Q1–Q7 on rev p were **AOD4184A / LCSC C99124**, chosen for budget and reliability. That call replaces the recommendation below. The numbers in this note are historical and are not rewritten.

**Rev q (2026-09-26):** Q1–Q7 are **NCE4080K / C191380** again. The 3.3 V gate problem is handled with four **SLM27524CA-DG / C2921387** drivers on `/V12_RAW`, not with another FET. See `docs/HARDWARE_STATUS_rev_q.md`.

## Recommendation

**This note recommended keeping NCE4080K** and not swapping to DMTH4004LK3. Quintin later chose AOD4184A instead. The numbers below are unchanged.

DMTH4004LK3 publishes 5 mΩ at VGS = 4.5 V, and this board never makes 4.5 V. Its VGS(th) maximum is 3.0 V. An STM32F407 GPIO high is about 3.3 V, so a worst-case DMTH is only 0.3 V above threshold. That is less overdrive than the NCE (VGS(th) max 2.5 V). The 5 mΩ line is the wrong number for this gate.

The part worth building as a later prototype, if Quintin wants a logic-level drop-in and still no gate driver, is **Infineon IPD90N04S4L-04 / LCSC C536903**. It is the only part in this set with both a VGS(th) max of 2.2 V and a guaranteed RDS(on) at 4.5 V (5.5 mΩ max) that is tighter than the NCE’s 7 mΩ at 10 V. RDS(on) at 3.3 V is still not guaranteed. Measure the drain-source drop on a fuel-pump load at VGS = 3.3 V, cold and hot, before any BOM edit.

AOD4184A is stocked and cheap. It is not a stronger choice here: VGS(th) max is 2.6 V, and 9.5 mΩ is only guaranteed at 4.5 V.

A gate driver to about 10 V would make the existing NCE 7 mΩ rating real. That is a schematic change, and it is outside this note.

None of these parts put back the VND14NV04-E protections (current limit, thermal shutdown, internal clamp).

## What the board actually drives

MCU is STM32F407VGT6, 3.3 V GPIO, through the existing 12 Ω series resistors R1–R7. No gate driver, charge pump, or extra transistor.

Steady gate current is leakage. The 12 Ω resistor does not drop a meaningful DC voltage, so VGS sits at the GPIO high, about 3.3 V. Suitability is the RDS(on) curve at that voltage, not the pin’s milliamp rating. Gate charge on these parts is tens of nanocoulombs. An STM32 pin sourcing on the order of 20 mA charges that in a few microseconds, which is enough for injector pulses and for idle or boost PWM.

| Channel | Parts | Load the FET sees |
|---|---|---|
| Q1–Q4 injectors | gate R1–R4, ballast R8–R11 (12 Ω), US1M D1–D4, SMAJ33A D5–D8 | High-Z injectors. The 12 Ω ballast alone limits a shorted output to about 14 V / 12 Ω ≈ 1.2 A. One 12 Ω injector plus the ballast is about 0.6 A. Two 12 Ω injectors in parallel plus the ballast is still about 1 A. Pulsed. |
| Q5 fuel-pump LS | gate R5 only | No ballast, no flyback, no TVS. Continuous while the pump runs. In-tank pumps are commonly several amps up to the mid-teens. |
| Q6 idle / VVT, Q7 boost | gate R6, R7 only | No clamp. Usually around an amp, PWM. |

Package ID of 50–100 A is the rating with the case held at 25 °C. It is not the current a 90 × 60 mm board can sink. The fuel-pump FET is the one that cares about RDS(on) at 3.3 V. Injector loss stays small even if RDS(on) is several times the headline number, as long as the FET is actually enhanced and not dropping volts out of the pulse.

## LCSC prices (2026-09-24)

USD, LCSC ladder, “ships now” stock on that date. Prices move.

| Part | LCSC | Stock | 1 pc | 100 pc | Package on LCSC |
|---|---|---:|---:|---:|---|
| NCE4080K | **C191380** | 21,822 | $0.283 | $0.155 | TO-252-2L |
| DMTH4004LK3-13 | **C260930** | 9,514 | $0.598 | $0.367 | TO-252 |
| IPD90N04S4L-04 | **C536903** | 927 | $1.008 | $0.620 | TO-252-3 |
| AOD4184A | **C99124** | 17,795 | $0.347 (min 5) | $0.233 at 150 | TO-252 |

Seven FETs is one ECU. At 100 pieces (about 14 boards) the IPD is about four times the NCE. IPD stock of 927 is about 130 boards, and it is thin next to the NCE.

NCE4080K is a JLCPCB **extended** part (same C191380), not a basic/zero-loading-fee part.

## Comparison

Datasheet maxima unless noted. VGS(th) is at ID = 250 µA (Infineon: ID = 35 µA). No part below guarantees RDS(on) at 3.3 V or at 2.5 V.

| | NCE4080K | DMTH4004LK3-13 | IPD90N04S4L-04 | AOD4184A |
|---|---|---|---|---|
| Maker | NCE | Diodes Inc. | Infineon OptiMOS-T2 | AOS |
| LCSC | C191380 | C260930 | C536903 | C99124 |
| VDS | 40 V | 40 V | 40 V | 40 V |
| ID (package, Tc = 25 °C) | 80 A (56 A at 100 °C) | 100 A (also 100 A at 100 °C) | 90 A at VGS = 10 V (84 A at 100 °C) | 50 A (13 A at Ta) |
| Package | TO-252-2L | TO-252 (DPAK, 2 leads + tab) | PG-TO252-3 | TO-252 |
| RDS(on) max at ≤ 4.5 V | not specified | **5 mΩ** at 4.5 V, 50 A (typ 4 mΩ) | **5.5 mΩ** at 4.5 V, 45 A (typ 4.6 mΩ) | **9.5 mΩ** at 4.5 V, 15 A |
| RDS(on) max at 10 V | **7 mΩ** at 20 A (LCSC PDF; a second NCE PDF prints 6.6 mΩ max / 5.4 mΩ typ) | 3 mΩ at 50 A (typ 2.4 mΩ) | 3.8 mΩ at 90 A (typ 3.2 mΩ) | 7 mΩ at 20 A |
| VGS(th) min / typ / max | 1.2 / 1.8 / **2.5 V** | 1 / — / **3 V** | 1.2 / 1.7 / **2.2 V** | 1.7 / 2.1 / **2.6 V** |
| Overdrive at 3.3 V above Vth max | 0.8 V | 0.3 V | 1.1 V | 0.7 V |
| RDS guaranteed at 3.3 V? | No. Only 10 V. | No. Only 4.5 V and 10 V. | No. Only 4.5 V and 10 V. | No. Only 4.5 V and 10 V. |
| 3.3 V GPIO, no driver | Turns on (Vth max 2.5 V). On-resistance in the car is unknown, and it gets worse cold (high Vth) and hot (RDS rises). Fine for ~1 A injectors if it is actually enhanced. Fuel-pump current needs a measurement. | Worst-case part is barely on at 3.3 V, and it is off if the rail sags to 3.0 V. The 5 mΩ spec does not apply. | Best overdrive in this set, and the 4.5 V spec is at least in the direction of a 3.3 V gate. Still a bench measurement before a fuel pump. | Slightly less overdrive than the NCE, and a higher 4.5 V RDS than the NCE’s 10 V number. |
| DPAK land | The footprint was drawn for this TO-252-2L. Pitch 4.56 mm vs LCSC P4.57. | Same JEDEC DPAK pitch (e = 2.286 mm). Drop-in. | Same outer-lead pitch. Middle lead is drain and sits in the gap; see below. | Same TO-252 land. Drop-in. |
| Single-pulse EAS | 750 mJ (LCSC PDF; another NCE PDF prints 670 mJ) | 90 mJ (L = 0.2 mH) | 95 mJ (ID = 45 A) | not used for the pick |
| Other | Discrete FET. Qg listed by LCSC as 61 nC. PD 80 W at Tc = 25 °C. No PCB RthJA on the short sheet. | AEC-Q101. Qg typ 35 nC at 4.5 V, 83 nC max at 10 V. PD 3.9 W (Ta) / 180 W (Tc). | AEC-Q101. Qg 46 nC at 10 V. RthJC 2.1 K/W. VGS +20 / −16 V. | Industrial. Qg 14 nC typ at 4.5 V, 27 nC typ at 10 V. PD 2.3 W (Ta) / 50 W (Tc). |

Sources: NCE PDF linked from LCSC C191380 (the sheet already cited in `docs/HARDWARE_STATUS_rev_o.md`); Diodes DMTH4004LK3 datasheet (DS37792); Infineon IPD90N04S4L-04 datasheet and the Infineon product page (VGS(th) 1.2–2.2 V, RDS 5.5 mΩ at 4.5 V, EAS 95 mJ, RthJC 2.1 K/W); AOS AOD4184A datasheet.

Also checked and not carried as candidates:

- **onsemi FDD8447L / LCSC C247783** (about 3,500 in stock, about $0.71 / $0.48 at 1 / 100). LCSC quotes the datasheet bullets: 8.5 mΩ max at 10 V, 11 mΩ max at 4.5 V, and lists VGS(th) as 3 V. Higher 4.5 V resistance than the IPD or the DMTH, and the same 3 V threshold problem as the DMTH.
- **Taiwan Semi TSM051N04LCP.** Datasheet: VGS(th) max 2.5 V (same as the NCE), RDS(on) 7 mΩ max at 4.5 V and 5.1 mΩ max at 10 V. The JLCPCB line showed no stock. Threshold max does not beat the NCE.

No TO-252 / DPAK part turned up on LCSC with RDS(on) actually guaranteed at 2.5 V in the 40 V class. Parts that do publish 2.5 V RDS (for example some AON PowerPAKs) are a different land.

## Footprint

`footprints/DPAK.kicad_mod` is a 2-lead + tab pattern, Infineon PG-TO252 style:

| | `microcore-fp:DPAK` |
|---|---|
| Gate pad 1 | (−3.1, −2.28) mm, 2.2 × 1.2 mm |
| Source pad 3 | (−3.1, +2.28) mm, 2.2 × 1.2 mm |
| Lead pitch | **4.56 mm** center to center |
| Drain tab pad 2 | (3.2, 0) mm, **6.4 × 5.8 mm** |
| Gap between gate and source pads | 3.36 mm (inner edges at y = ±1.68 mm) |

JEDEC TO-252 basic pitch is e ≈ 2.29 mm, so the outer leads (gate and source) are about 4.58 mm apart. NCE’s own drawing is e = 2.186–2.386 mm, lead width 0.66–0.86 mm. DMTH’s drawing is e = 2.286 mm, lead width 0.64–0.88 mm. The 1.2 mm pad is wider than the lead. Pitch and tab match the land already accepted for the NCE in rev o. No footprint redraw is required for any part in the table.

TO-252-3 (IPD, AOD, DMTH) still has a middle lead. On a DPAK that lead is drain, tied to the tab inside the package. There is no middle pad on this footprint. The lead is about 1 mm wide and sits in the 3.36 mm gap, so it does not land on the gate or source pad. It is not soldered. The drain connection remains the tab. Pinout stays pin 1 gate, pin 2 drain, pin 3 source, which is the symbol Q1–Q7 already use.

TO-252-2L (NCE) is the same body with that middle lead omitted.

## Thermal and current

Headline ID assumes the tab is held at 25 °C. Infineon’s note on this DPAK: continuous current is bond-wire limited, and with RthJC = 2.1 K/W the die could carry more than the package lead. The PG-TO252 PCB footnote on the OptiMOS-T2 DPAK series (printed on the sibling IPD90N04S4-04 sheet; the L sheet itself confirms RthJC and EAS) is about **62 K/W** on a minimal footprint and about **40 K/W** with 6 cm² of drain copper (40 × 40 × 1.5 mm FR4, 70 µm, one layer, still air). NCE does not publish an RthJA. The DPAK body is the same order.

Those 6 cm² are on the **drain** tab. Source is the GND pour. Each drain is its own net (injector or LS), so the tab does not heat-sink into the ground plane. Seven FETs share a board of about 90 × 60 mm. A full 6 cm² island per drain is optimistic.

SPEC already calls for the FETs on the lid-facing copper with a gap-pad. The tab is live (it is the load), so that pad has to be electrically insulating. The stack is not sized in this repo. Until someone measures it, treat the PCB figures as the pessimistic limit and the gap-pad as an unquantified improvement.

Illustration only, not a measured board temperature: ambient 85 °C, junction kept to 150 °C, RthJA 40 K/W gives about **1.6 W**. At 62 K/W the budget is about **1.0 W**.

| If the real RDS(on) at 3.3 V, hot, is | Continuous current at 1.6 W |
|---|---:|
| 5 mΩ (IPD’s 4.5 V max, if you actually get it) | ~18 A |
| 7 mΩ (NCE’s 10 V max, if you actually get it) | ~15 A |
| 15 mΩ | ~10 A |
| 30 mΩ | ~7 A |
| 50 mΩ | ~6 A |

A fuel pump in the mid-teens only fits that budget if RDS(on) really is down around the 5–10 mΩ datasheet lines **and** the copper or the gap-pad is at least as good as the 40 K/W example. A part sitting a few hundred millivolts above threshold can be tens or hundreds of milliohms. At 100 mΩ a 10 A pump is 10 W in the package, which a DPAK on this board will not shed. That is the failure mode of a high VGS(th) max on Q5, and it is why the DMTH’s 5 mΩ at 4.5 V is not a reason to swap.

Injector channels, at about 1 A, dissipate under 0.1 W even at 50 mΩ. They are a gate-drive question only in the sense of pulse-voltage drop, not a copper question.

Q5–Q7 have no flyback diode and no TVS. Turn-off energy goes into the FET as avalanche. NCE’s single-pulse EAS on the LCSC PDF is 750 mJ. DMTH is 90 mJ and the IPD is 95 mJ. A small solenoid at 1 A is only a few millijoules; a pump or a stubborn solenoid can be more, and repetitive avalanche is a separate rating. Swapping to the DMTH or the IPD does not make the unclamped low-sides safer. The missing diode is still leftover 3 in `docs/HARDWARE_STATUS_rev_o.md`.

## 40 V and the SMAJ33A

All four parts are 40 V, which matches the injector clamp already on the board (SMAJ33A, LCSC C143131, D5–D8). SMAJ33A standoff is 33 V. Breakdown for that type is about 36.7–40.6 V, and the 10/1000 µs clamping voltage is **53.3 V**. That is above 40 V. US1M (D1–D4) is the flyback that should catch a normal injector spike near the 12 V rail. The TVS is the second line. A hard clamp event can still put the drain above the FET’s DC rating. That is true for the NCE, the DMTH, and the IPD alike, so it does not pick a winner. A 60 V FET would sit above that clamp voltage and would be a different design than the 40 V class this note was asked to stay in.

Low-side drains have neither diode nor TVS. Their voltage limit is the FET itself.

## What would change the recommendation

1. A measured RDS(on) of the stuffed NCE at VGS = 3.3 V, at room temperature and hot, at a few amps. If that number stays low enough for the pump Quintin actually uses, the NCE can stay with no driver.
2. The same measurement on an IPD90N04S4L-04 before putting C536903 in `bom_replace_microcore-o.csv`.
3. A gate driver to ~10 V, if the measurement says the NCE is not enhanced. That is new schematic parts, not a FET swap.
4. Flyback diodes on Q5–Q7, whatever FET is fitted. Separate from this comparison.

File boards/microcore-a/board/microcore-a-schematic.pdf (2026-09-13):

1 | 2 | 3 | 4 | 5 | 6
1 | 2 | 3 | 4 | 5 | 6

AB

C

D

AB

C

D Date: 2026-09-13

KiCad E.D.A. 10.0.6

Size: A4 | Rev: A Id: 1/1

Title: Micro Core

File: microcore.kicad_sch

Sheet: /

Core EFI

Hellen-One frame scaffolding — place modules before Create Board fab

Firmware board: coreefi_micro

PCB basename: microcore (no dashes/underscores)

## Micro Core frame scaffold

Place Hellen modules: MCU F4, input lite,

## 4-ch inj, 4-ch 5V ign, 3x LS, power TE 776231-1 vertical AMPSEAL 35

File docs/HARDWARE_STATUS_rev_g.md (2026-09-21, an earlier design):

> **Superseded for current work:** see [HARDWARE_STATUS_rev_h.md](HARDWARE_STATUS_rev_h.md) (rev h→i, 2026-09-21).

# Micro Core hardware status — rev g

**Date:** 2026-09-16 (Africa/Johannesburg)  
**Repo:** `quintinbannink42/micro-core` @ `main`  
**KiCad basename:** `microcore` (`BOARD_PREFIX=micro`, `BOARD_SUFFIX=core`, `BOARD_REVISION=g`)  
**Create Board artifacts:** `boards/microcore-g/` (CI green on rev-g GND pours commit)

## Verdict

**Not fab-ready yet.** Create Board / gerber/BOM/CPL/preview package exists and CI succeeded, but injector/LS power-stage protection parts and analog/Hall conditioning are still stubs, and KiCad DRC reports real connectivity concerns that need a design pass (or confirmed Hellen-merge false positives) before ordering.

## Inventory (`boards/microcore-g/`)

| Area | Present |
|---|---|
| Board gerbers | Yes — `board/gerber/microcore-g.*` (GTL/GBL/G1/G2/mask/silk/paste/outline/drill) |
| JLC BOM + CPL | Yes — `microcore-g-BOM-JLC.csv`, `microcore-g-CPL.csv` |
| Previews / iBOM / schematic PDF | Yes — `microcore-g.png`, `misc/*-top/bottom/outline/components.png`, `ibom.html`, schematic PDF |
| Frame package | Yes — `frame/core.*` gerbers + BOM/CPL/schematic/VRML |
| Warnings log | Yes — LCSC duplicate-partnumber warnings only |

Root `gerber/` also holds a parallel export set (F/B/In Cu, masks, drill, net, pdf, wrl).

## DRC summary (kicad-cli 9.0.2)

Command: `kicad-cli pcb drc --format report --severity-all --output … microcore.kicad_pcb`

| Category | Count | Notes |
|---|---:|---|
| padstack | 159 | Typical Hellen multi-module merge noise |
| solder_mask_bridge | 154 | Merge noise / module pads |
| **shorting_items** | **147** | **Must triage** — see below |
| holes_co_located | 118 | Module stitch / stacked holes |
| tracks_crossing | 69 | Correlates with shorts |
| silk_* | ~51 | Cosmetic |
| clearance | 28 | Includes module pad G (no-net) interactions |
| unconnected_items | 2 | Zone island + **J8 GND ↔ F.Cu GND zone** |
| starved_thermal | 1 | Thermal relief |
| other | few | lib mismatch, edge clearance, diff-pair VR_P/VR_N |

Top shorting net-pairs (unique pairs ~93):
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

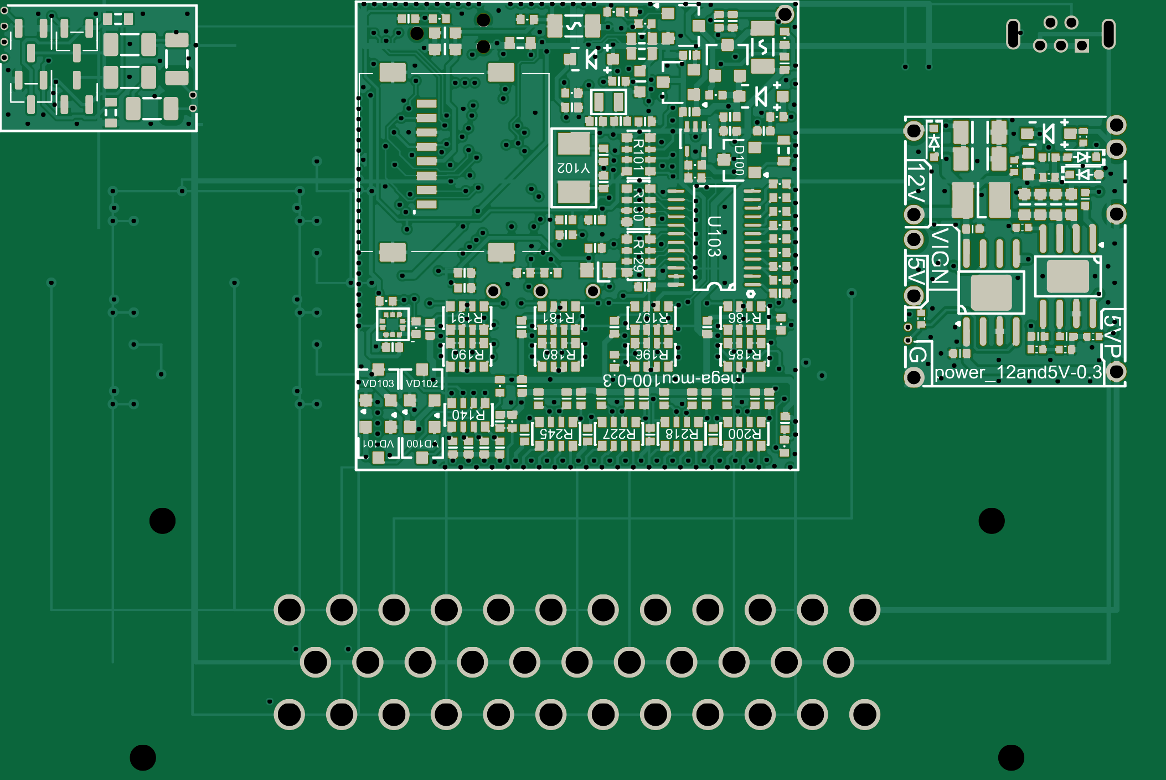
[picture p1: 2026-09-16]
boards/microcore-f/board/misc/microcore-f-bottom.png

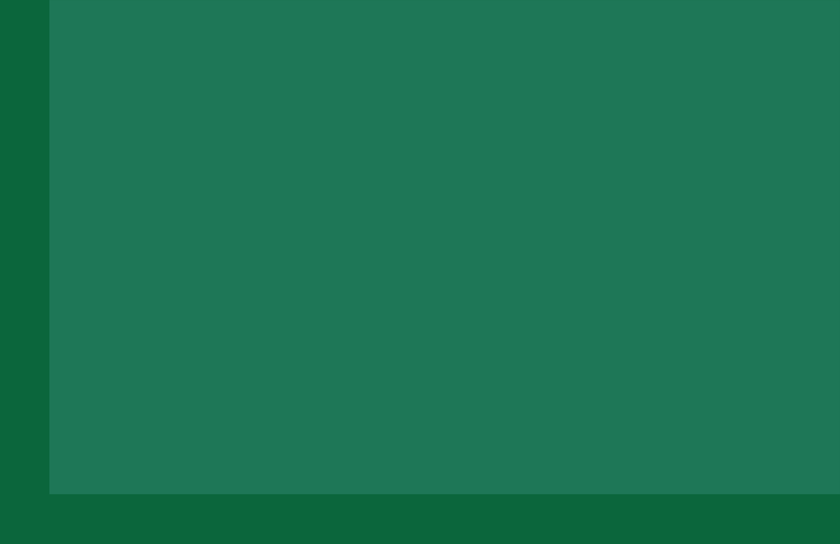
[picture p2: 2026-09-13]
boards/microcore-a/board/misc/microcore-a-top.png

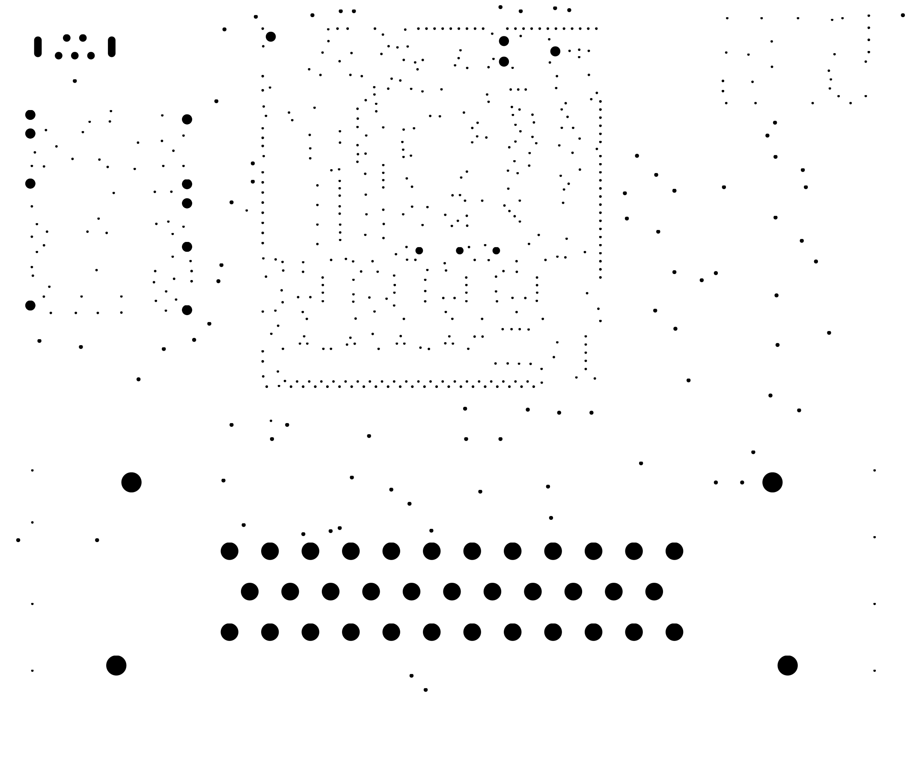
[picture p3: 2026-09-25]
boards/microcore-p/board/misc/microcore-p-outline.png

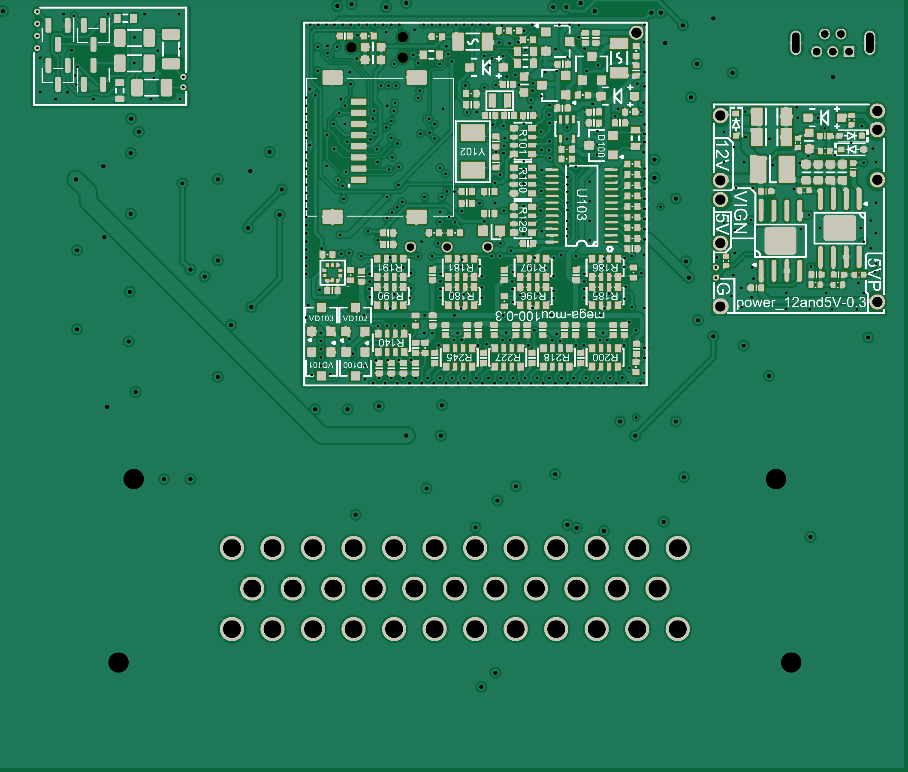
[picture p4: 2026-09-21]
boards/microcore-i/board/misc/microcore-i-bottom.png

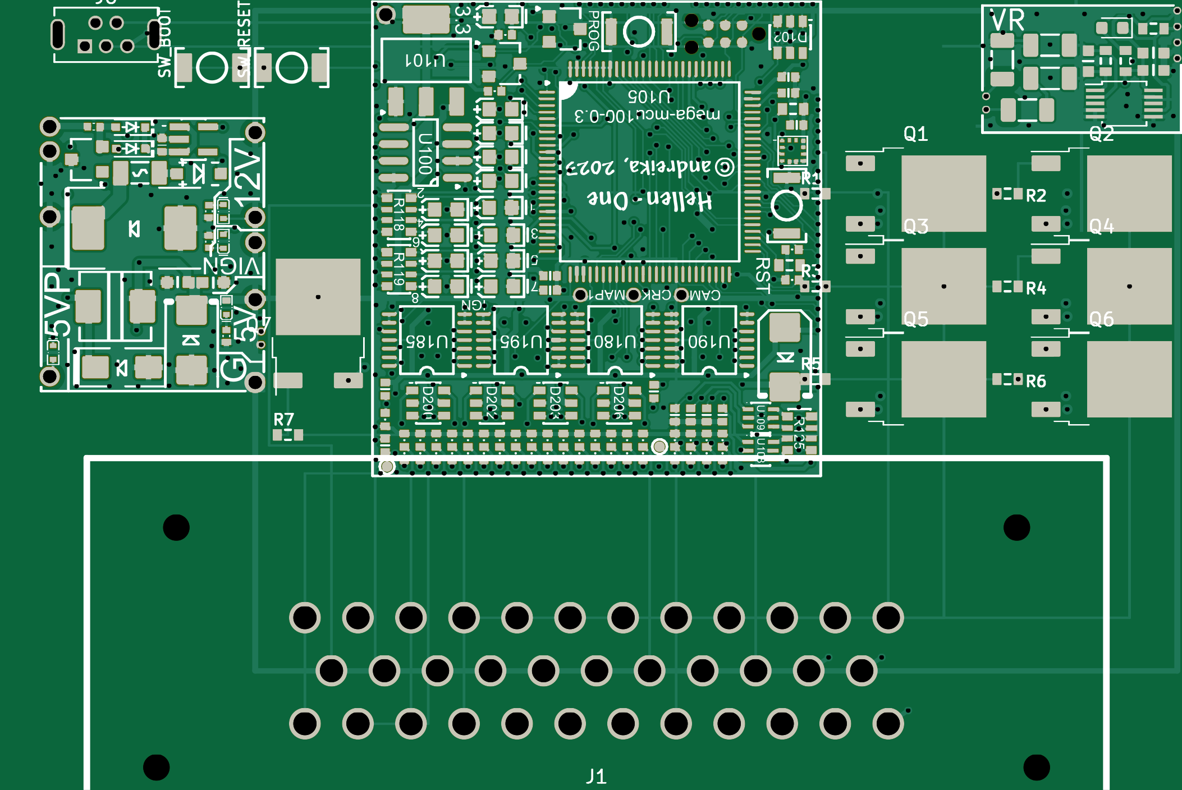
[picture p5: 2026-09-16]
boards/microcore-f/board/misc/microcore-f-top.png

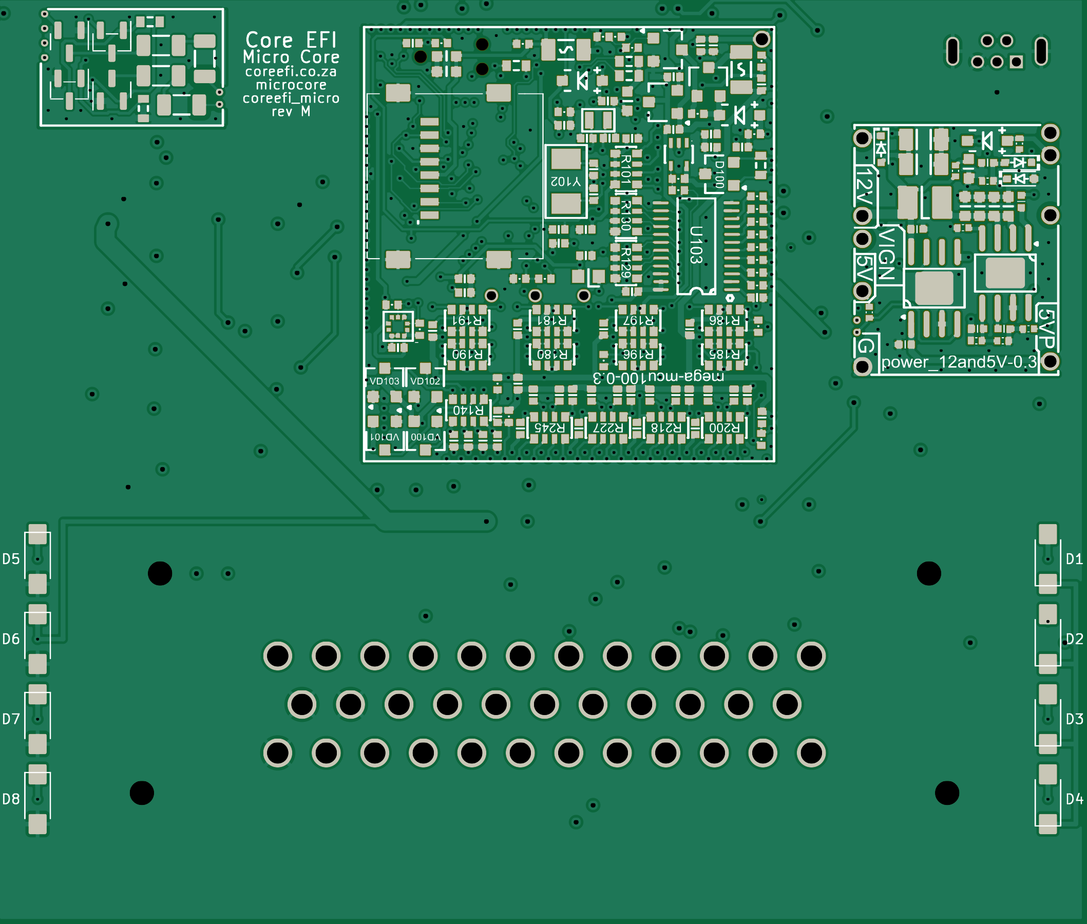
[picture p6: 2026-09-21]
boards/microcore-m/board/misc/microcore-m-bottom.png

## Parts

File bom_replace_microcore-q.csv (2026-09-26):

# removal example: R66006 would be removed from BOM
# R66006
# replacement example - replace specific fuse part number
# F42333310 | nSMD050-24V | SMD1206 | C70076
# VR module: vr-max9924/0.3 (was vr-discrete/0.5 on rev b)
# Note: hellen-one submodule points at quintinbannink42/hellen-one with
# vr-max9924/0.3 D751 comment aligned to LED-GREEN-0603 (matches mega-mcu100).
# rev q: Q1-Q7 back to NCE4080K (LCSC C191380). AOD4184A / C99124 rows removed.
# Gate drive is four Sillumin SLM27524CA-DG (LCSC C2921387) | UCC27524 class
# dual non-inverting low-side drivers. VDD is the existing /V12_RAW rail.
# 7 of 8 channels used (Q1-Q7). U4 channel A input is tied to GND; OUTA unused.
# Keep Hellen module mega-mcu100/0.3 and STM32F407VGT6 (LCSC C12345).
# PCB footprint for the FETs stays microcore-fp:DPAK (same land; not redrawn).
# Series gate resistors R1-R7 stay 12 ohm. MCU GPIO no longer drives the gates.
# Local bypass at each driver VDD: 100 nF C14663 + 1 uF C559769.
# 1 uF Samsung CL10A105KB8NNNC / C15849 was out of stock; C559769 is the
# YAGEO CC0603KRX7R9BB105 1 uF 50 V X7R 0603 substitute.
# LS clamps kept from rev p: D9-D11 US1M C112545 | D12-D14 SMAJ33A C143131.
# Injector D1-D8 and ballast R8-R11 unchanged.
# Comments are ASCII-only.
U105 | STM32F407VGT6 | LQFP100 | C12345
# Frame power FETs + gate resistors (7 channels)
Q1 | NCE4080K | DPAK | C191380
Q2 | NCE4080K | DPAK | C191380
Q3 | NCE4080K | DPAK | C191380
Q4 | NCE4080K | DPAK | C191380
Q5 | NCE4080K | DPAK | C191380
Q6 | NCE4080K | DPAK | C191380
Q7 | NCE4080K | DPAK | C191380
R1 | 12 | R0603 | C22783
R2 | 12 | R0603 | C22783
R3 | 12 | R0603 | C22783
R4 | 12 | R0603 | C22783
R5 | 12 | R0603 | C22783
R6 | 12 | R0603 | C22783
R7 | 12 | R0603 | C22783
# Dual low-side gate drivers (SOIC-8 | microcore-fp:SOIC-8)
U1 | SLM27524CA-DG | SOIC-8 | C2921387
U2 | SLM27524CA-DG | SOIC-8 | C2921387
U3 | SLM27524CA-DG | SOIC-8 | C2921387
U4 | SLM27524CA-DG | SOIC-8 | C2921387
# Driver VDD bypass | one 100 nF and one 1 uF at each IC
C1 | 100n | C0603 | C14663
C3 | 100n | C0603 | C14663
C5 | 100n | C0603 | C14663
C7 | 100n | C0603 | C14663
C2 | 1u | C0603 | C559769
C4 | 1u | C0603 | C559769
C6 | 1u | C0603 | C559769
C8 | 1u | C0603 | C559769
# SPEC injector protection: 2nd 12 ohm high-Z ballast + UF flyback + 33V TVS (DO-214AC)
R8 | 12 | R0603 | C22783
R9 | 12 | R0603 | C22783
R10 | 12 | R0603 | C22783
R11 | 12 | R0603 | C22783
D1 | US1M | DO214AC | C112545
D2 | US1M | DO214AC | C112545
D3 | US1M | DO214AC | C112545
D4 | US1M | DO214AC | C112545
D5 | SMAJ33A | DO214AC | C143131
D6 | SMAJ33A | DO214AC | C143131
D7 | SMAJ33A | DO214AC | C143131
D8 | SMAJ33A | DO214AC | C143131
# LS Q5-Q7 flyback + TVS (same parts as D1-D8; no ballast)
D9 | US1M | DO214AC | C112545
D10 | US1M | DO214AC | C112545
D11 | US1M | DO214AC | C112545
D12 | SMAJ33A | DO214AC | C143131
D13 | SMAJ33A | DO214AC | C143131
D14 | SMAJ33A | DO214AC | C143131

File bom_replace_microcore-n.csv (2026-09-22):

# removal example: R66006 would be removed from BOM
# R66006
# replacement example - replace specific fuse part number
# F42333310 | nSMD050-24V | SMD1206 | C70076
# VR module: vr-max9924/0.3 (was vr-discrete/0.5 on rev b)
# Note: hellen-one submodule points at quintinbannink42/hellen-one with
# vr-max9924/0.3 D751 comment aligned to LED-GREEN-0603 (matches mega-mcu100).
# rev n cost-down: keep Hellen module mega-mcu100/0.3 (do not switch to mega-mcu64).
# STM32F429VIT6 LCSC C92002 -> STM32F407VGT6 LQFP-100.
# Locked LCSC C12345 (JLCPCB/LCSC: ST STM32F407VGT6 | LQFP-100 14x14 | in stock).
# Rejected candidates: C15815 is TI TLC2252CDR op-amp; C2252 is a 22.1184 MHz crystal.
# Q5-Q7 LS DPAKs and gate R5-R7 are removed from schematic and PCB (rows dropped).
# Injector protection unchanged: Q1-Q4 | gate R1-R4 | ballast R8-R11 | US1M + SMAJ33A.
U105 | STM32F407VGT6 | LQFP100 | C12345
# Frame injector FETs + gate Rs (4 channels only)
Q1 | VND14NV04-E | DPAK | C155647
Q2 | VND14NV04-E | DPAK | C155647
Q3 | VND14NV04-E | DPAK | C155647
Q4 | VND14NV04-E | DPAK | C155647
R1 | 12 | R0603 | C22783
R2 | 12 | R0603 | C22783
R3 | 12 | R0603 | C22783
R4 | 12 | R0603 | C22783
# SPEC injector protection: 2nd 12 ohm high-Z ballast + UF flyback + 33V TVS (DO-214AC)
R8 | 12 | R0603 | C22783
R9 | 12 | R0603 | C22783
R10 | 12 | R0603 | C22783
R11 | 12 | R0603 | C22783
D1 | US1M | DO214AC | C112545
D2 | US1M | DO214AC | C112545
D3 | US1M | DO214AC | C112545
D4 | US1M | DO214AC | C112545
D5 | SMAJ33A | DO214AC | C143131
D6 | SMAJ33A | DO214AC | C143131
D7 | SMAJ33A | DO214AC | C143131
D8 | SMAJ33A | DO214AC | C143131

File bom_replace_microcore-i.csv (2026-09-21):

# removal example: R66006 would be removed from BOM
# R66006
# replacement example - replace specific fuse part number
# F42333310 | nSMD050-24V | SMD1206 | C70076
# VR module: vr-max9924/0.3 (was vr-discrete/0.5 on rev b)
# Note: hellen-one submodule points at quintinbannink42/hellen-one with
# vr-max9924/0.3 D751 comment aligned to LED-GREEN-0603 (matches mega-mcu100).
# rev i: J8 GND stitch (via+tracks); carry rev h BOM assigns
SW_BOOT | BTN | SMD-2_2.9x3.9x1.7 | C115357
SW_RESET | BTN | SMD-2_2.9x3.9x1.7 | C115357
# Frame power-stage FETs + gate Rs (were on misc BOM without LCSC / absent from JLC BOM)
Q1 | VND14NV04-E | DPAK | C155647
Q2 | VND14NV04-E | DPAK | C155647
Q3 | VND14NV04-E | DPAK | C155647
Q4 | VND14NV04-E | DPAK | C155647
Q5 | VND14NV04-E | DPAK | C155647
Q6 | VND14NV04-E | DPAK | C155647
Q7 | VND14NV04-E | DPAK | C155647
R1 | 12 | R0603 | C22783
R2 | 12 | R0603 | C22783
R3 | 12 | R0603 | C22783
R4 | 12 | R0603 | C22783
R5 | 12 | R0603 | C22783
R6 | 12 | R0603 | C22783
R7 | 12 | R0603 | C22783

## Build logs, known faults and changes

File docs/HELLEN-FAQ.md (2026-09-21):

# Hellen One tips for Micro Core

Copied/adapted from [rusefi/hellen-example](https://github.com/rusefi/hellen-example) FAQ. Firmware board name remains `coreefi_micro`; KiCad project/board file basename is `microcore` (no `-` or `_`).

## Create Board CI

On push to default branch `main`, `.github/workflows/create-board.yaml` calls `andreika-git/hellen-one` Create Board:

1. Checkout with submodules
2. Install KiCad 10
3. `hellen-one/kicad/bin/export.sh` — gerbers, drill, pos, BOM, schematic PDF, VRML from `microcore.kicad_pcb` / `microcore.kicad_sch`
4. Docker build + gerber merge into `boards/microcore-m/` (revision letter from `revision.txt`)
5. Commit/push fab outputs when on `main`

A pull-request branch may *run* Create Board; **fab files are only pushed when the workflow runs on `main`**. After merging rev **m**, the next green run on `main` should create `boards/microcore-m/`. Manual path: GitHub → Actions → **Create Board** → Run workflow (on `main`).

Daily workflows bump `hellen-one` and `kicad6-libraries` submodule pointers.

## Naming and origin rules

- **No dashes or underscores** in `.kicad_pcb` filenames (`microcore.kicad_pcb`, not `micro_core` / `micro-core`).
- `revision.txt`: `BOARD_PREFIX` + `BOARD_SUFFIX` must equal the KiCad basename (`micro` + `core` → `microcore`).
- `bom_replace_${PREFIX}${SUFFIX}-${REVISION}.csv` → `bom_replace_microcore-a.csv`.
- **`aux_axis_origin` required** in the PCB (drill/place origin).
- Origin at **bottom-left** in KiCad Y-down (`aux_axis_origin 0 60` for 90×60 board); **no negative place coordinates** after drill-origin export (hellen-one/gerbmerge limitation).
- Default branch must be **`main`** or CI will not push fab results.

## Intended Hellen modules (from SPEC)

Locked modules-v1: `mega-mcu100/0.3` (Value `Module:mega-mcu100/0.3`), `power_12and5V/0.3`, `vr-max9924/0.3`, USB Mini-B (`USB_B_Mini` / `USB-MINI-B-VERTICAL`), TE `776231-1`; frame sheets INJ4/LS3/ANALOG/HALL with DPAKs. Skip mcu/0.7, output/0.3, input/0.1, wbo, knock, motor-driver, ign8, optional can.

## Firmware

See https://github.com/rusefi/fw-custom-hellen144-f4 and https://github.com/rusefi/rusefi/wiki/Custom-Firmware

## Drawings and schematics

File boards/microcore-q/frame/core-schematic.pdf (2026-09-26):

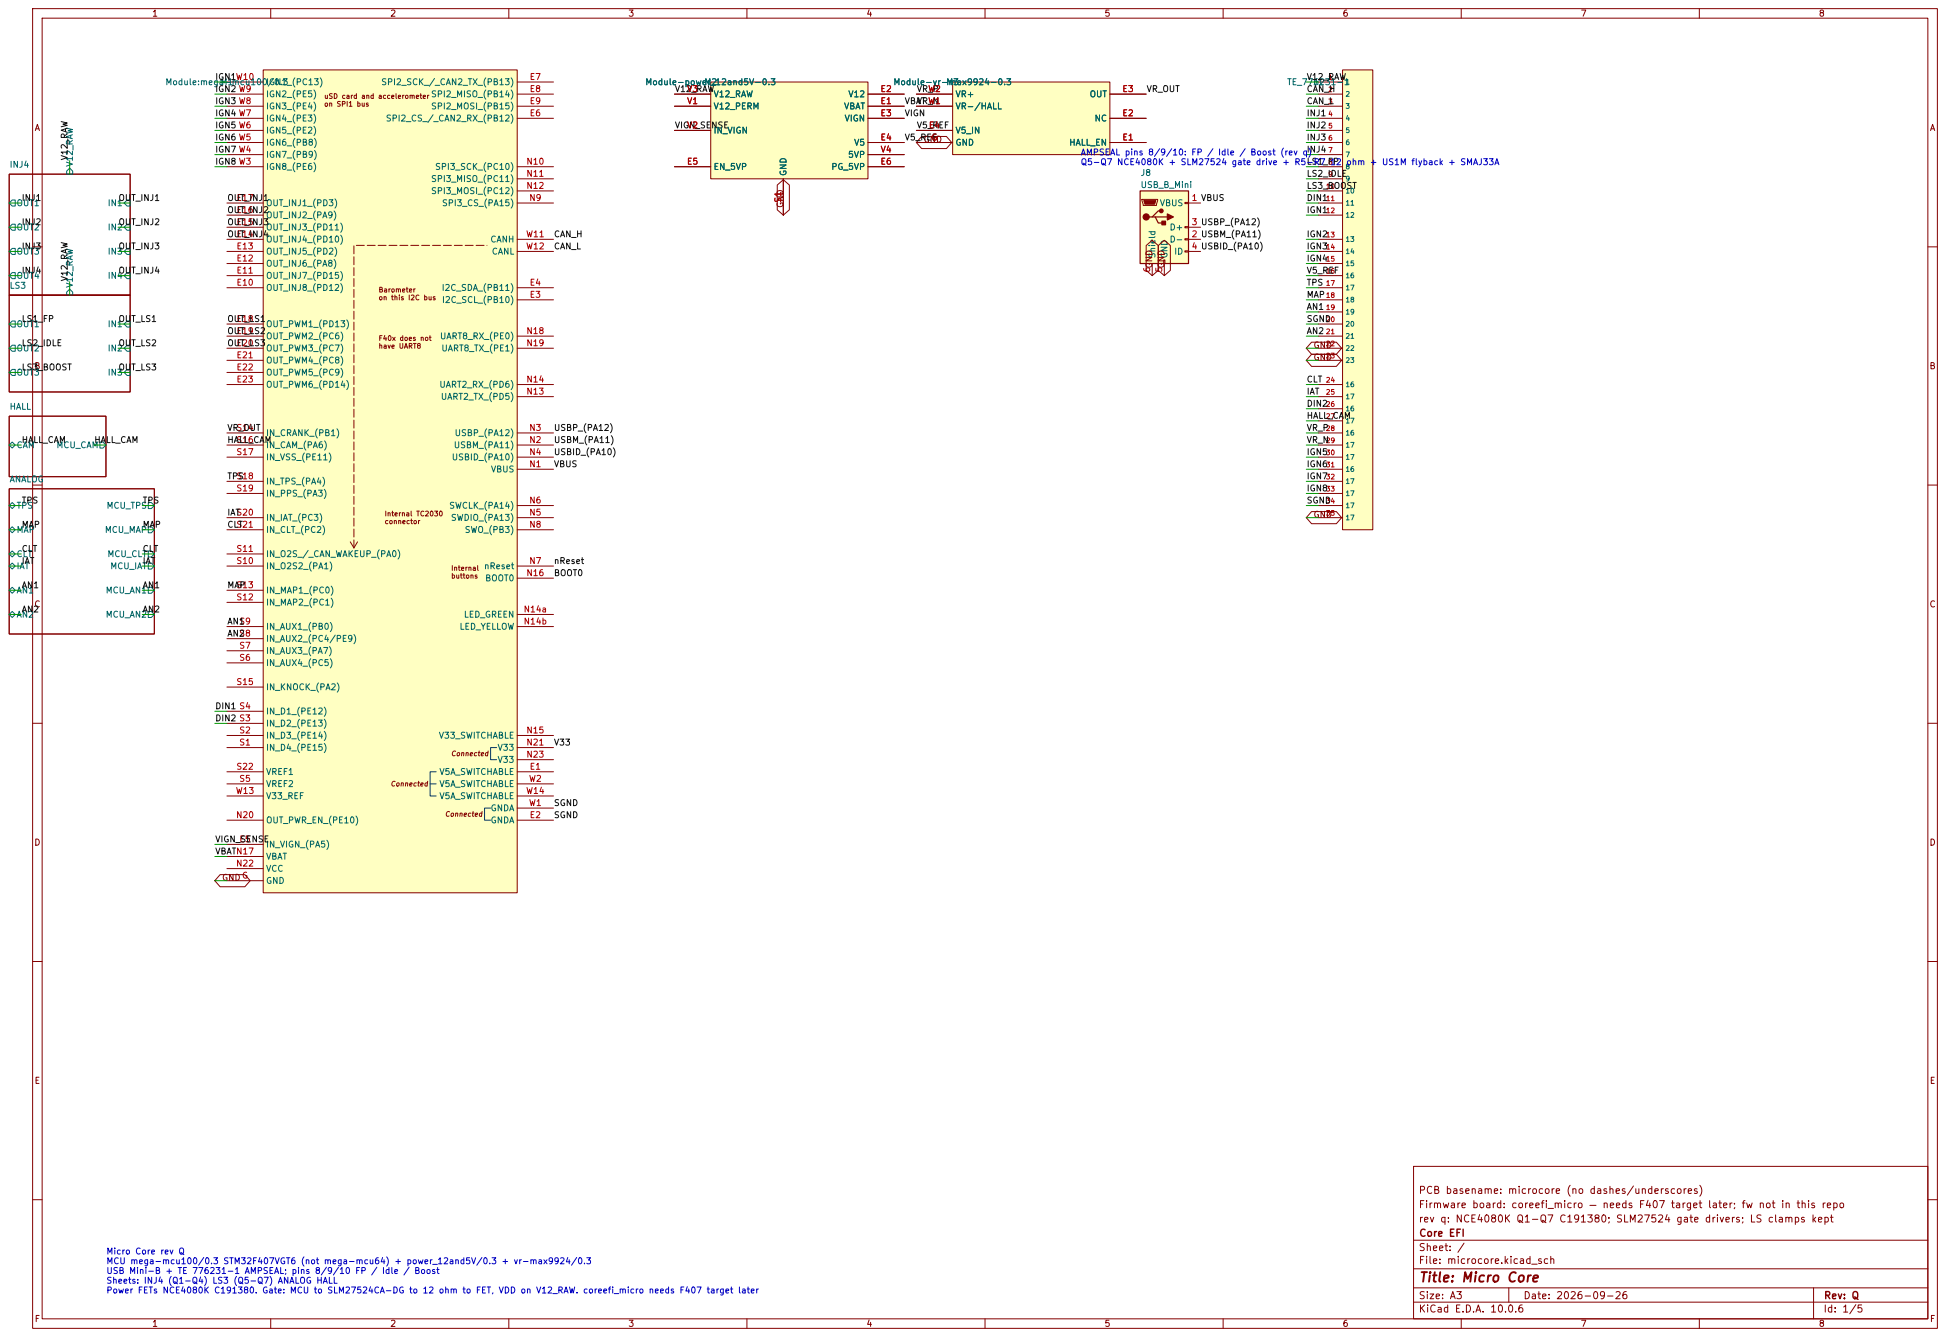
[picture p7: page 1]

PCB basename: microcore (no dashes/underscores)
Firmware board: coreefi_micro — needs F407 target later; fw not in this repo
Core EFI rev q: NCE4080K Q1-Q7 C191380; SLM27524 gate drivers; LS clamps kept

Micro Core rev Q MCU mega-mcu100/0.3 STM32F407VGT6 (not mega-mcu64) + power_12and5V/0.3 + vr-max9924/0.3 USB Mini-B + TE 776231-1 AMPSEAL; pins 8/9/10 FP / Idle / Boost Sheets: INJ4 (Q1-Q4) LS3 (Q5-Q7) ANALOG HALL Power FETs NCE4080K C191380. Gate: MCU to SLM27524CA-DG to 12 ohm to FET, VDD on V12_RAW. coreefi_micro needs F407 target later

Size: A3 | Rev: Q | F Date: 2026-09-26
KiCad E.D.A. 10.0.6 | Id: 1/5

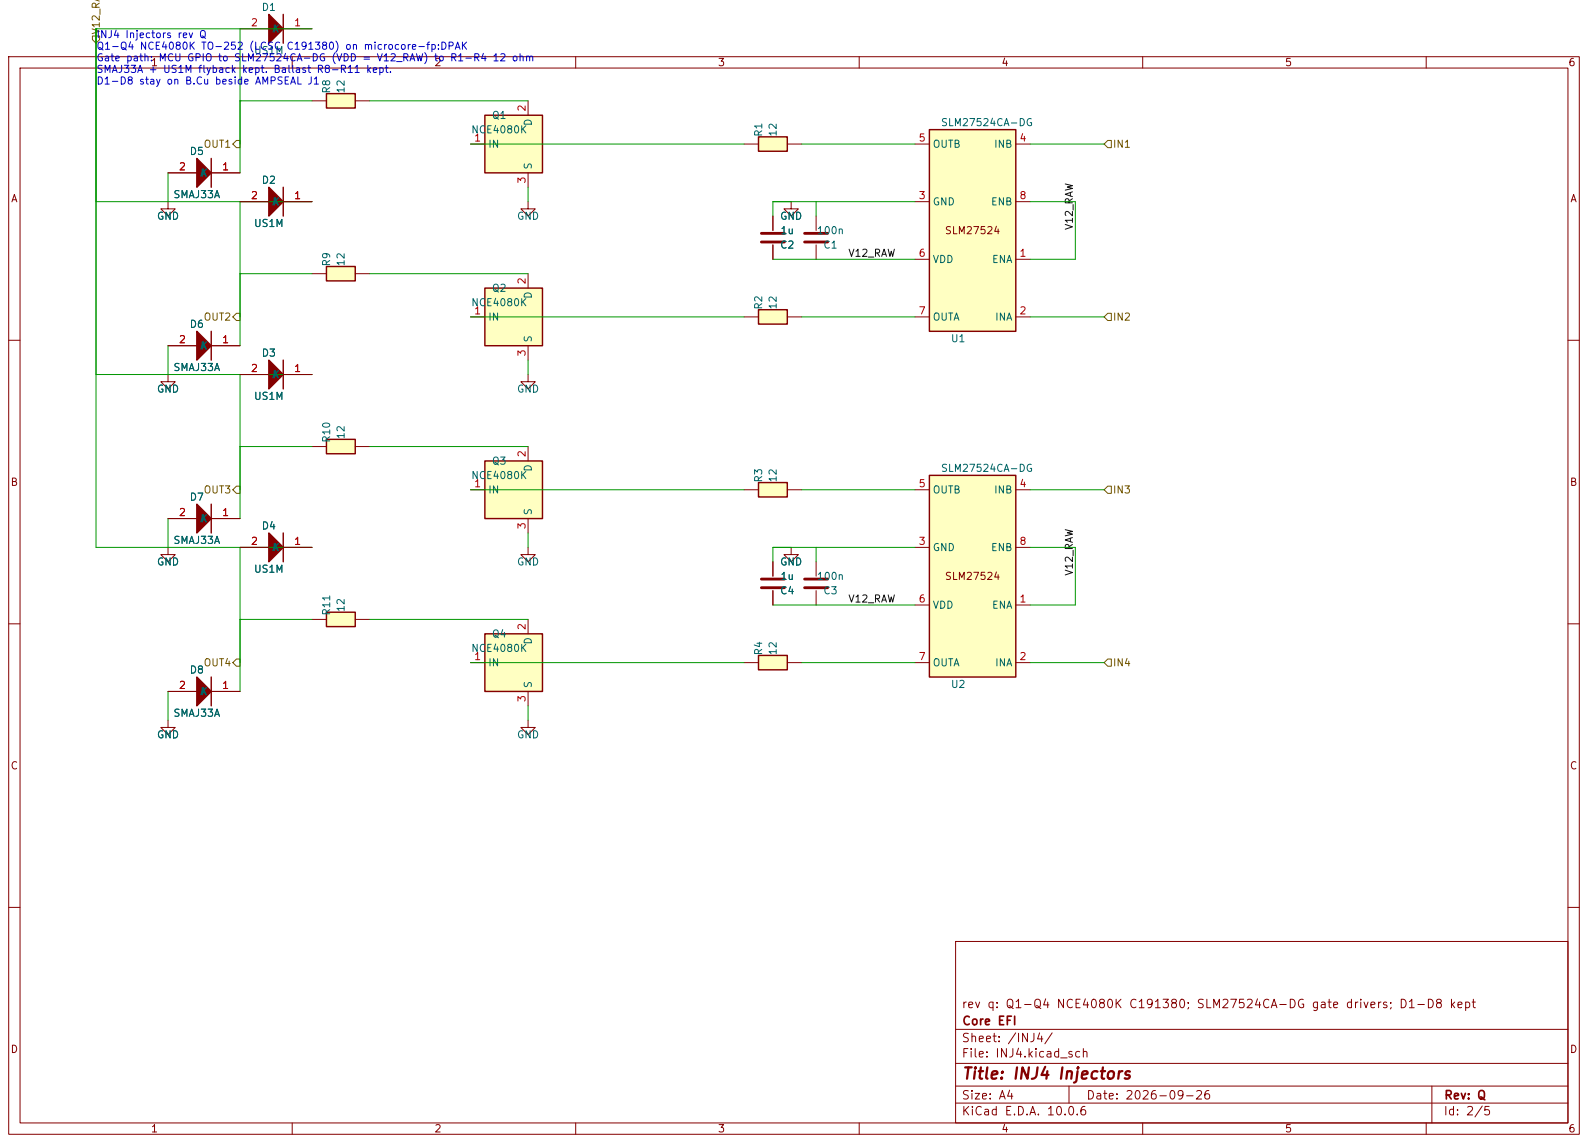
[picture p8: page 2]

INJ4 Injectors rev Q
Q1-Q4 NCE4080K TO-252 (LCSC C191380) on microcore-fp:DPAK
Gate path: MCU GPIO to SLM27524CA-DG (VDD = V12_RAW) to R1-R4 12 ohm

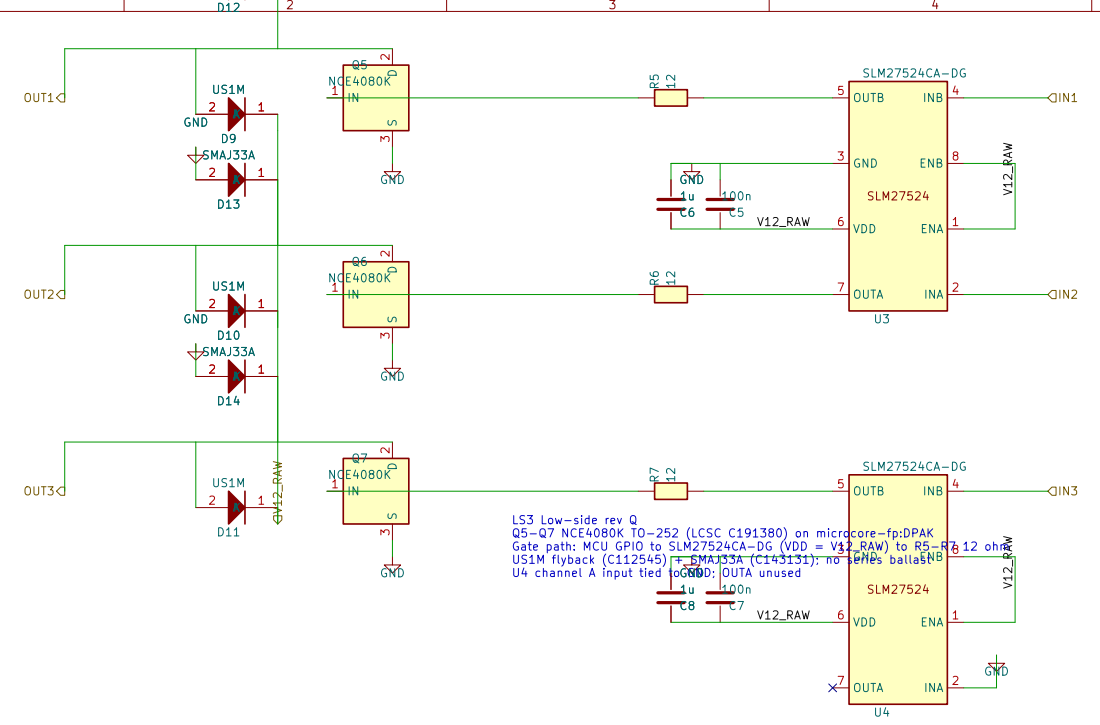
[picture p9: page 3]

LS3 Low-side rev Q
Q5-Q7 NCE4080K TO-252 (LCSC C191380) on microcore-fp:DPAK
Gate path: MCU GPIO to SLM27524CA-DG (VDD = V12_RAW) to R5-R7 12 ohm

NCE4080K gates driven to V12_RAW by SLM27524; US1M + SMAJ33A kept GND

Core EFI rev q: Q5-Q7 NCE4080K C191380; SLM27524CA-DG; US1M + SMAJ33A kept

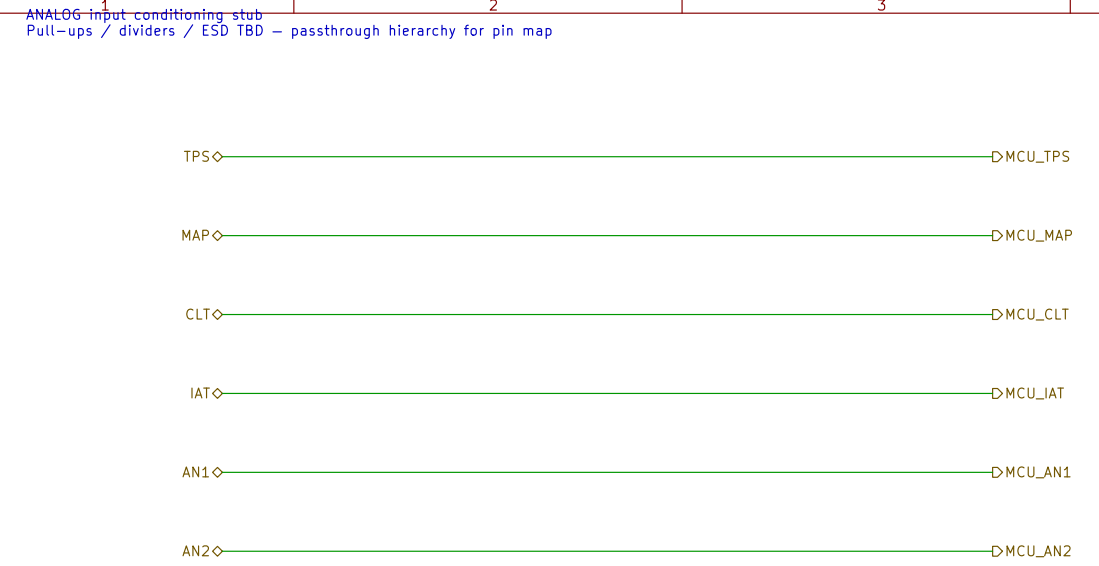
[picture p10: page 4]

ANALOG input conditioning stub Pull-ups / dividers / ESD TBD — passthrough hierarchy for pin map

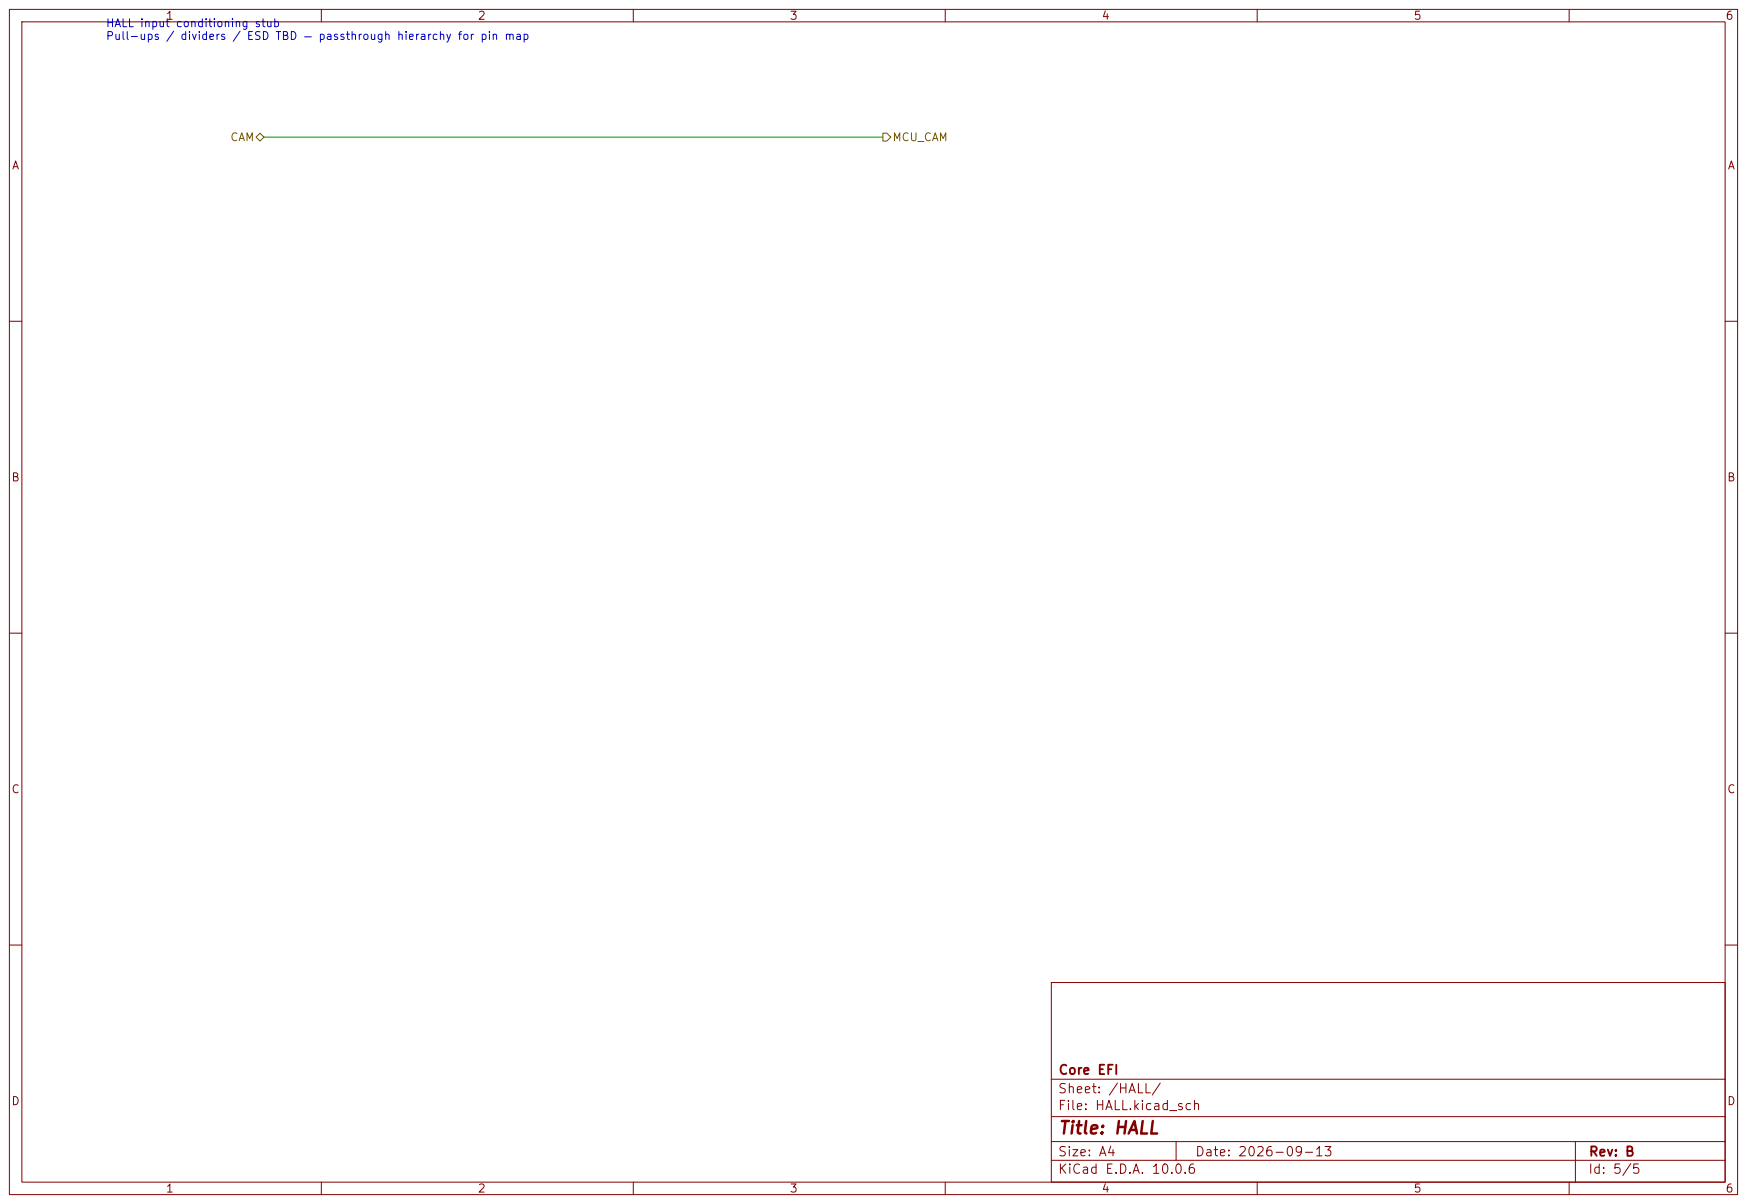
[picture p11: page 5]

HALL input conditioning stub Pull-ups / dividers / ESD TBD — passthrough hierarchy for pin map

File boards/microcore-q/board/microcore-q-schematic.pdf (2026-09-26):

1 | 2 | 3 | 4 | 5 | 6 | 7 | 8
1 | 2 | 3 | 4 | 5 | 6 | 7 | 8

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
F Date: 2026-09-26
KiCad E.D.A. 10.0.6
Size: A3 | Rev: Q Id: 1/5

## Title: Micro Core

File: microcore.kicad_sch

Sheet: /

Core EFI rev q: NCE4080K Q1-Q7 C191380; SLM27524 gate drivers; LS clamps kept

Firmware board: coreefi_micro — needs F407 target later; fw not in this repo

PCB basename: microcore (no dashes/underscores)

# OUT1 OUT2 OUT3

IN1

IN2

IN3

LS3 | V12_RAW
CAM | MCU_CAM

HALL

TPS MAP

CLT
IAT AN1
AN2 | MCU_TPS MCU_MAP MCU_CLT MCU_IAT MCU_AN1 MCU_AN2
ANALOG | V12_RAW

# OUT1 OUT2 OUT3 OUT4

IN1

IN2

IN3

IN4

INJ4

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
10 10

11 11

12 12

13 13

14 14

15 15

16 16

17 17

18 18

19 19

20 20

21 21

22 22

23 23

16 24

17 25

16 26

17 27

16 28

17 29

17 30

16 31

17 32

17 33

17 34

17 35

TE_776231-1 J1 HALL_EN | E1 NC | E2 OUT | E3
V5_IN E4 | GND G
VR-/HALL W1 | VR+ W2 Module-vr-max9924-0.3 M3

VBUS 1 D- 2 D+ 3

ID 4 GND

# 5 Shield 6

J8USB_B_Mini uSD card and accelerometer on SPI1 bus Barometer on this I2C bus F40x does not have UART8

Internal TC2030
connector Connected | Connected
Internal buttons Connected V5A_SWITCHABLE | E1 GNDA | E2
I2C_SCL_(PB10) | E3 I2C_SDA_(PB11) | E4

IN_VIGN_(PA5) E5

SPI2_CS_/_CAN2_RX_(PB12) | E6
SPI2_SCK_/_CAN2_TX_(PB13) | E7
SPI2_MISO_(PB14) | E8
SPI2_MOSI_(PB15) | E9 OUT_INJ8_(PD12) E10 | OUT_INJ7_(PD15) E11 | OUT_INJ6_(PA8) E12 | OUT_INJ5_(PD2) E13 | OUT_INJ4_(PD10) E14 | OUT_INJ3_(PD11) E15 | OUT_INJ2_(PA9) E16 | OUT_INJ1_(PD3) E17 | OUT_PWM1_(PD13) E18 | OUT_PWM2_(PC6) E19 | OUT_PWM3_(PC7) E20 | OUT_PWM4_(PC8) E21 | OUT_PWM5_(PC9) E22 | OUT_PWM6_(PD14) E23 | GND G
VBUS | N1 USBM_(PA11) | N2 USBP_(PA12) | N3 USBID_(PA10) | N4
SWDIO_(PA13) | N5 SWCLK_(PA14) | N6
nReset | N7
SWO_(PB3) | N8
SPI3_CS_(PA15) | N9

SPI3_SCK_(PC10) N10
SPI3_MISO_(PC11) N11
SPI3_MOSI_(PC12) N12 UART2_TX_(PD5) N13 UART2_RX_(PD6) N14

LED_GREEN N14a
LED_YELLOW N14b
V33_SWITCHABLE | N15 BOOT0 | N16

VBAT N17

UART8_RX_(PE0) N18 UART8_TX_(PE1) N19 OUT_PWR_EN_(PE10) N20

V33 N21

VCC N22

V33 | N23 IN_D4_(PE15) S1 | IN_D3_(PE14) S2 | IN_D2_(PE13) S3 | IN_D1_(PE12) S4

VREF2 S5

IN_AUX4_(PC5) S6 | IN_AUX3_(PA7) S7 | IN_AUX2_(PC4/PE9) S8 | IN_AUX1_(PB0) S9
IN_O2S2_(PA1) S10 | IN_O2S_/_CAN_WAKEUP_(PA0) S11
IN_MAP2_(PC1) S12 | IN_MAP1_(PC0) S13

IN_CRANK_(PB1) S14

IN_KNOCK_(PA2) S15

IN_CAM_(PA6) S16
IN_VSS_(PE11) S17

IN_TPS_(PA4) S18
IN_PPS_(PA3) S19

IN_IAT_(PC3) S20
IN_CLT_(PC2) S21
VREF1 S22 | GNDA | W1
| V5A_SWITCHABLE | W2
IGN8_(PE6) W3 | IGN7_(PB9) W4 | IGN6_(PB8) W5 | IGN5_(PE2) W6 | IGN4_(PE3) W7 | IGN3_(PE4) W8 | IGN2_(PE5) W9 | IGN1_(PC13) W10 | CANH W11 CANL W12
V33_REF W13 | V5A_SWITCHABLE W14

Module:mega-mcu100/0.3 M1
VBAT | E1 V12 | E2
VIGN | E3
V5 | E4
EN_5VP E5 | PG_5VP | E6 GND S1

V12_PERM V1

IN_VIGN V2

V12_RAW V3

5VP | V4 Module-power_12and5V-0.3 M2 | GND
GND | GND

GND

GND

GND GND

GND

LS1_FP | OUT_LS1 | USBM_(PA11)

INJ2

LS2_IDLE | OUT_INJ4

INJ1

INJ4 V12_RAWINJ3

LS1_FP

LS3_BOOST DIN1

AN1 MAP

TPS

V5_REF

IGN4

IGN3

IGN2

# IGN1 CAN_H

V12_RAW

CAN_L USBID_(PA10) | LS2_IDLE DIN2 CLT CLT
IAT | AN2

SGND

# AN2 CLT

IAT

IAT | HALL_CAM VR_P VR_N IGN5 IGN6 IGN7 IGN8

SGND HALL_CAM

LS3_BOOST | OUT_LS3 V12_RAW

OUT_INJ1 OUT_INJ2 OUT_INJ3

TPS MAP | OUT_LS2 HALL_CAM

OUT_LS1 OUT_LS2 OUT_LS3

TPS

VR_OUT HALL_CAM

# OUT_INJ3 DIN2

IGN6
IGN7
IGN8

VIGN_SENSE

# CAN_L V33 BOOT0 USBP_(PA12)

USBM_(PA11) OUT_INJ1

# nReset SGND

SGND

OUT_INJ2 OUT_INJ4 | CAN_H

VBUS USBID_(PA10) AN1

# IAT CLT MAP

VBAT

TPS

AN2 | MAP

AN1
AN2
AN1 | DIN1
IGN2 | V12_RAW

VIGN_SENSE

VBAT VIGN

IGN3

INJ4

INJ3

INJ2

IGN1

INJ1 USBP_(PA12) VBUS

V5_REF

VR_P
VR_N
IGN5 | V5_REF

VR_OUT

IGN4

Micro Core rev Q MCU mega-mcu100/0.3 STM32F407VGT6 (not mega-mcu64) + power_12and5V/0.3 + vr-max9924/0.3 USB Mini-B + TE 776231-1 AMPSEAL; pins 8/9/10 FP / Idle / Boost Sheets: INJ4 (Q1-Q4) LS3 (Q5-Q7) ANALOG HALL Power FETs NCE4080K C191380. Gate: MCU to SLM27524CA-DG to 12 ohm to FET, VDD on V12_RAW. coreefi_micro needs F407 target later

AMPSEAL pins 8/9/10: FP / Idle / Boost (rev q) Q5-Q7 NCE4080K + SLM27524 gate drive + R5-R7 12 ohm + US1M flyback + SMAJ33A Module-power_12and5V-0.3 M2
VBAT | E1 V12 | E2
VIGN | E3
V5 | E4
EN_5VP E5 | PG_5VP | E6 GND S1

V12_PERM V1

IN_VIGN V2

V12_RAW V3

5VP | V4 Module-vr-max9924-0.3 M3 | HALL_EN | E1 NC | E2 OUT | E3
V5_IN E4 | GND G
VR-/HALL W1 | VR+ W2

# SMAJ33A GND
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

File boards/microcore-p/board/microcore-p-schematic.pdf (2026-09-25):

# ANALOG V12_RAW

# OUT1 OUT2 OUT3 OUT4

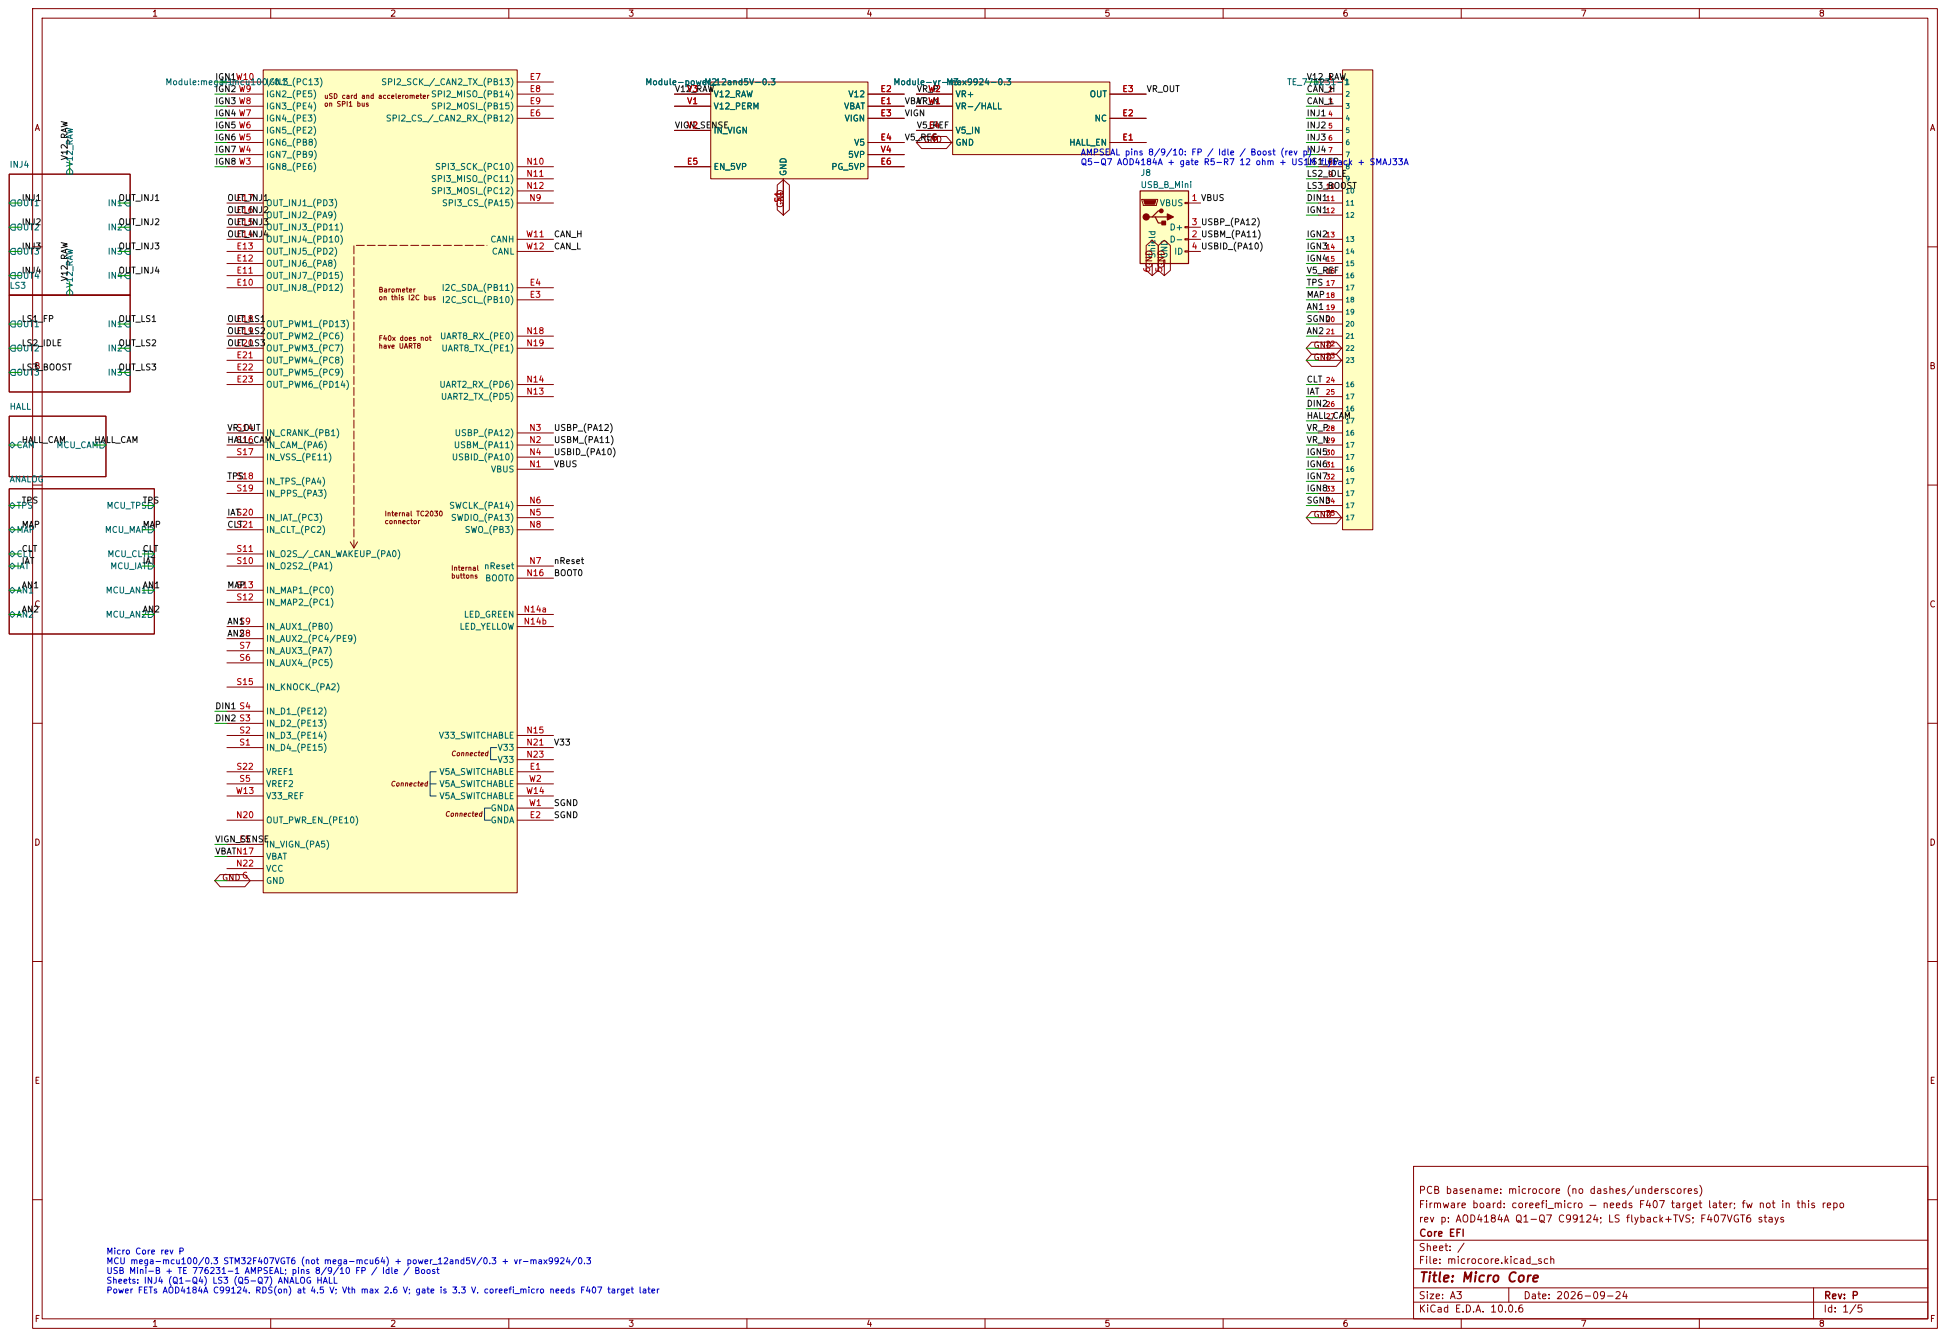
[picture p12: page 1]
F Date: 2026-09-24; Size: A3; Rev: P; OUT1 OUT2 OUT3; V12_RAW; CAM; MCU_CAM; HALL; TPS MAP; CLT IAT AN1; MCU_TPS MCU_MAP MCU_CLT MCU_IAT MCU_AN1 MCU_AN2; INJ4; TE_776231-1 J1 HALL_EN; E2 OUT; GND G; VR-/HALL W1; VR+ W2 Module-vr-max9924-0.3 M3; VBUS 1 D- 2 D+ 3; ID 4 GND; 5 Shield 6; J8USB_B_Mini uSD card and accelerometer on SPI1 bus; Barometer on this I2C bus F40x does not have UART8; Internal TC2030; connector Connected; Connected; Internal buttons Connected V5A_SWITCHABLE; E1 GNDA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

AMPSEAL pins 8/9/10: FP / Idle / Boost (rev p) Q5-Q7 AOD4184A + gate R5-R7 12 ohm + US1M flyback + SMAJ33A Module-power_12and5V-0.3 M2

TPS
IAT CLT MAP

PCB basename: microcore (no dashes/underscores)
Firmware board: coreefi_micro — needs F407 target later; fw not in this repo
Core EFI rev p: AOD4184A Q1-Q7 C99124; LS flyback+TVS; F407VGT6 stays

Sheet: /
File: microcore.kicad_sch
Title: Micro Core
KiCad E.D.A. 10.0.6

Micro Core rev P MCU mega-mcu100/0.3 STM32F407VGT6 (not mega-mcu64) + power_12and5V/0.3 + vr-max9924/0.3 USB Mini-B + TE 776231-1 AMPSEAL; pins 8/9/10 FP / Idle / Boost Sheets: INJ4 (Q1-Q4) LS3 (Q5-Q7) ANALOG HALL Power FETs AOD4184A C99124. RDS(on) at 4.5 V; Vth max 2.6 V; gate is 3.3 V. coreefi_micro needs F407 target later

# SMAJ33A GND R912 R812 K

# A 2 D3 US1M

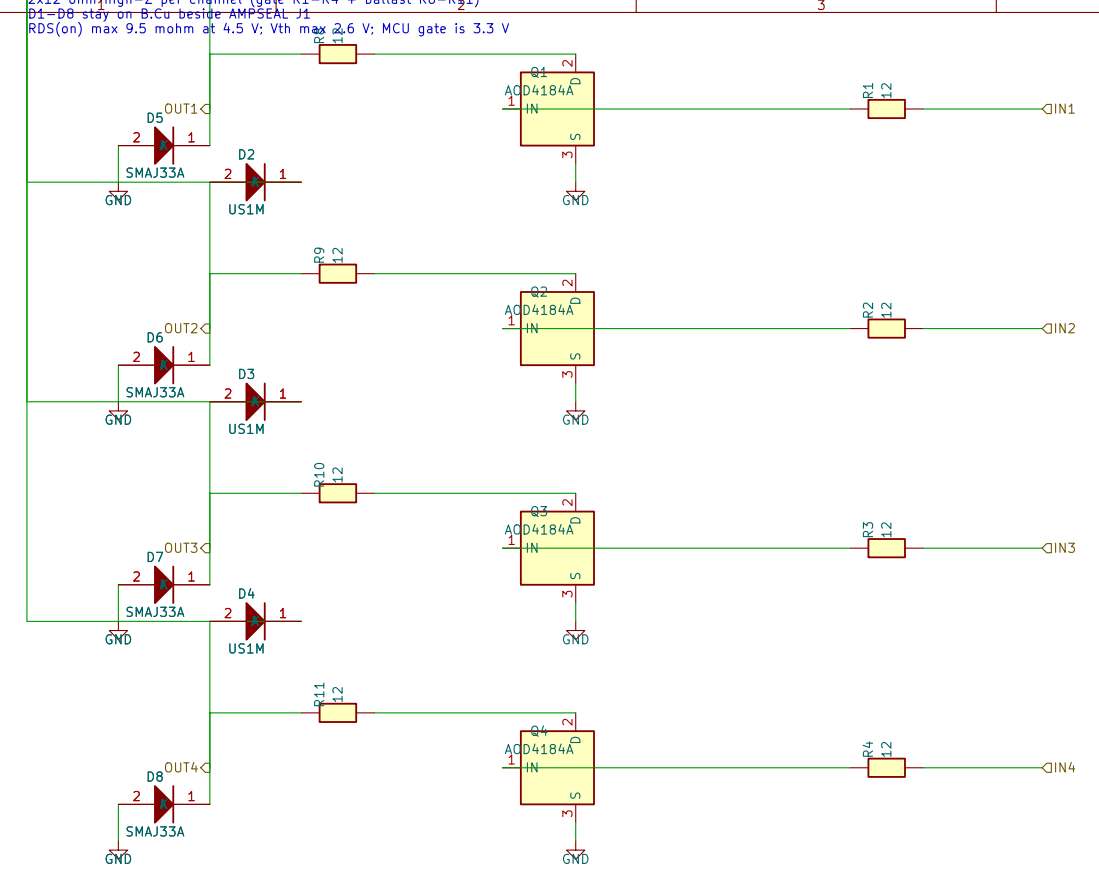
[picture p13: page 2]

INJ4 Injectors rev P
SMAJ33A (DO-214AC) + US1M UF flyback kept 2x12 ohm high-Z per channel (gate R1-R4 + ballast R8-R11) D1-D8 stay on B.Cu beside AMPSEAL J1 RDS(on) max 9.5 mohm at 4.5 V; Vth max 2.6 V; MCU gate is 3.3 V D4 US1M

Core EFI rev p: Q1-Q4 AOD4184A C99124; D1-D8 and R8-R11 kept

# A 2D10 US1M

A 2D12

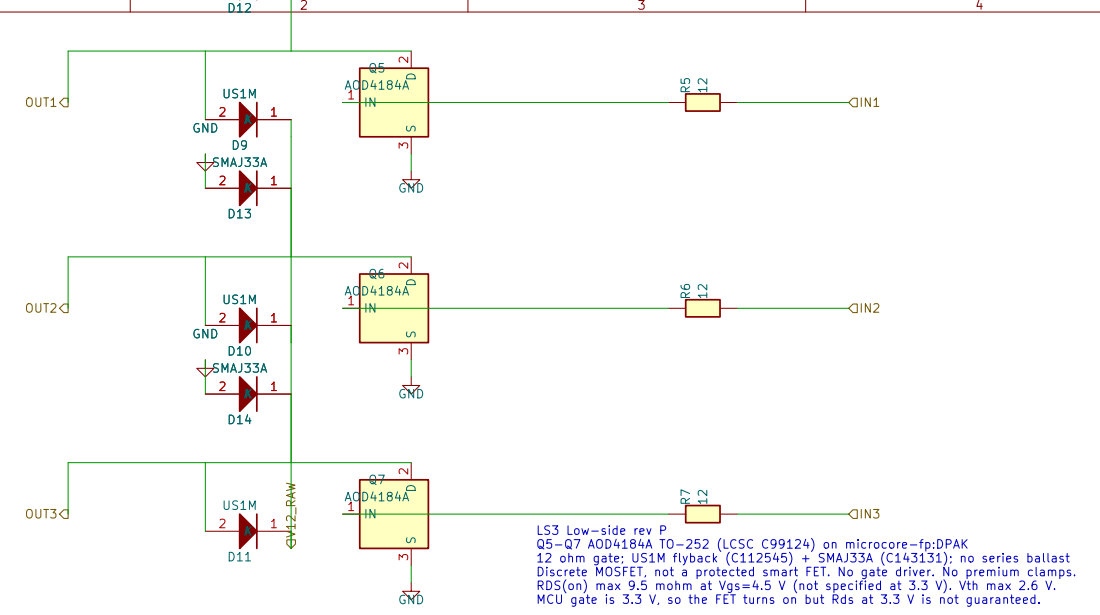
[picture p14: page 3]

AOD4184A K
RDS(on) max 9.5 mohm at Vgs=4.5 V (not specified at 3.3 V). Vth max 2.6 V. MCU gate is 3.3 V, so the FET turns on but Rds at 3.3 V is not guaranteed. D9 US1M
A 2 GND

12 ohm gate; US1M flyback (C112545) + SMAJ33A (C143131); no series ballast Discrete MOSFET, not a protected smart FET. No gate driver. No premium clamps.

RDS(on) at 4.5 V; Vth max 2.6 V; MCU gate 3.3 V; no gate driver
Core EFI rev p: Q5-Q7 AOD4184A C99124; US1M flyback + SMAJ33A

D Date: 2026-09-13; KiCad E.D.A. 10.0.6; Size: A4; Rev: B; Title: ANALOG; File: ANALOG.kicad_sch; Sheet: /ANALOG/; Core EFI; MCU_MAP; TPS; IAT CLT MAP; MCU_AN2 MCU_AN1 MCU_IAT MCU_CLT MCU_TPS

ANALOG input conditioning stub Pull-ups / dividers / ESD TBD — passthrough hierarchy for pin map

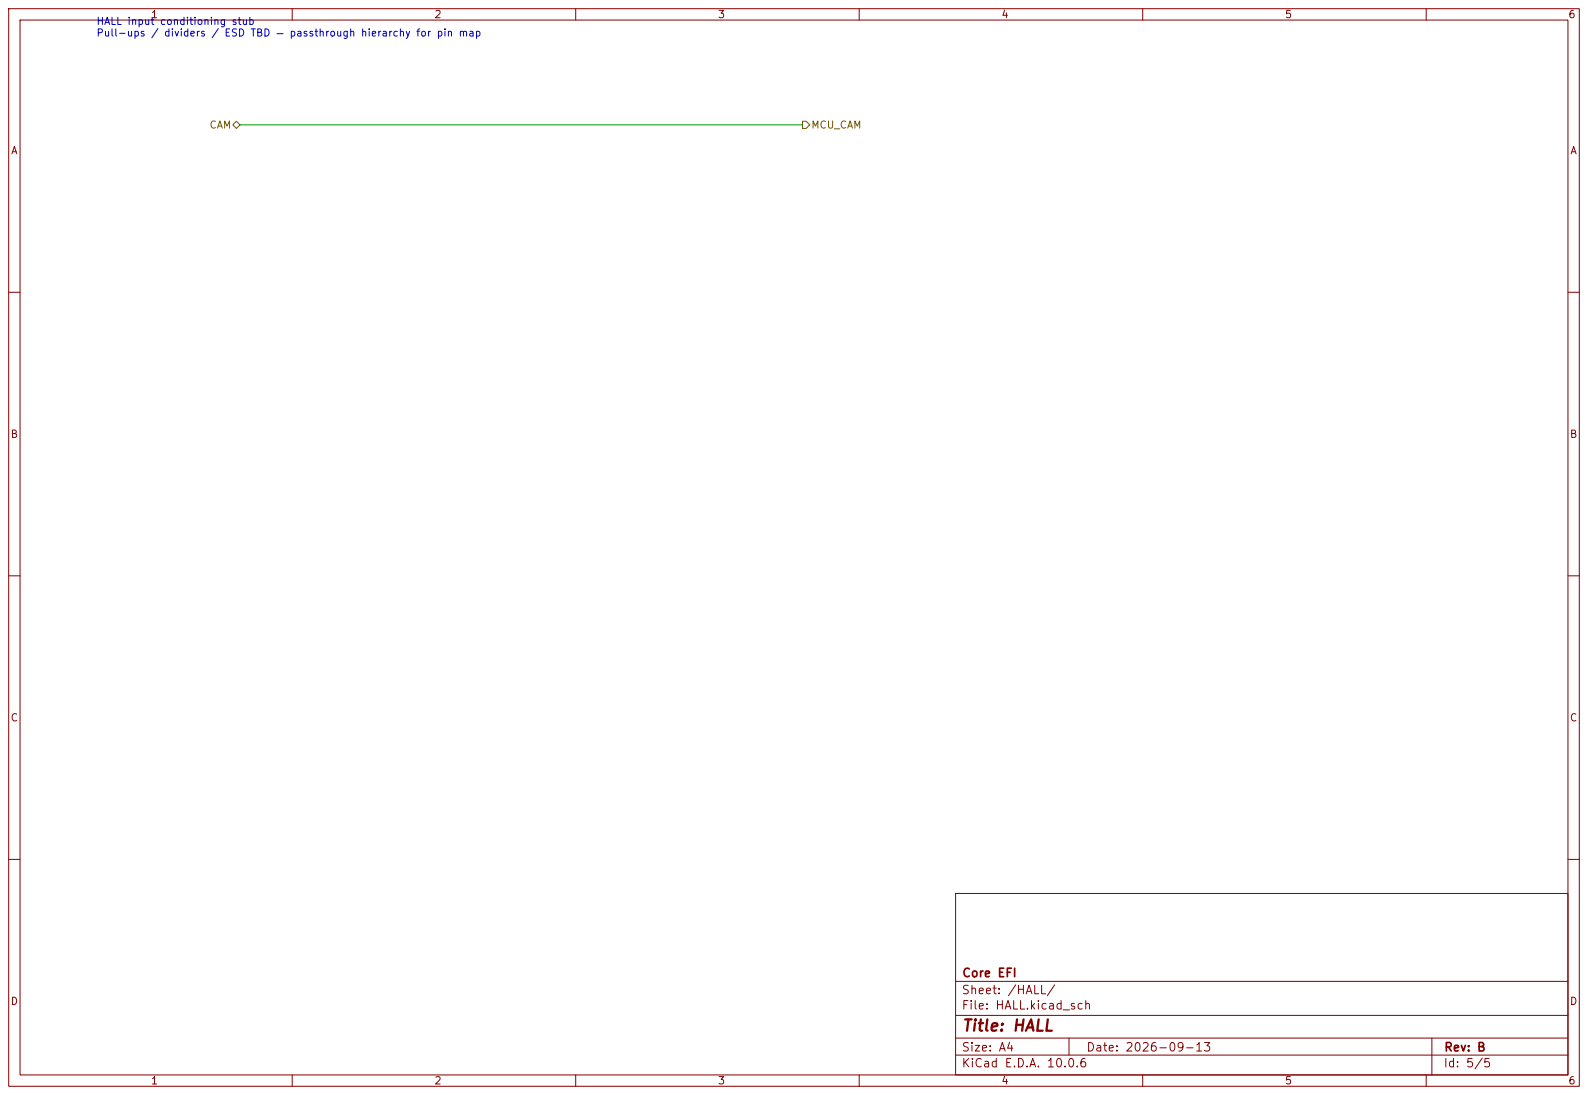
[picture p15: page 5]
D Date: 2026-09-13; KiCad E.D.A. 10.0.6; Size: A4; Rev: B; Title: HALL; File: HALL.kicad_sch; Sheet: /HALL/; Core EFI; CAM; MCU_CAM

HALL input conditioning stub Pull-ups / dividers / ESD TBD — passthrough hierarchy for pin map

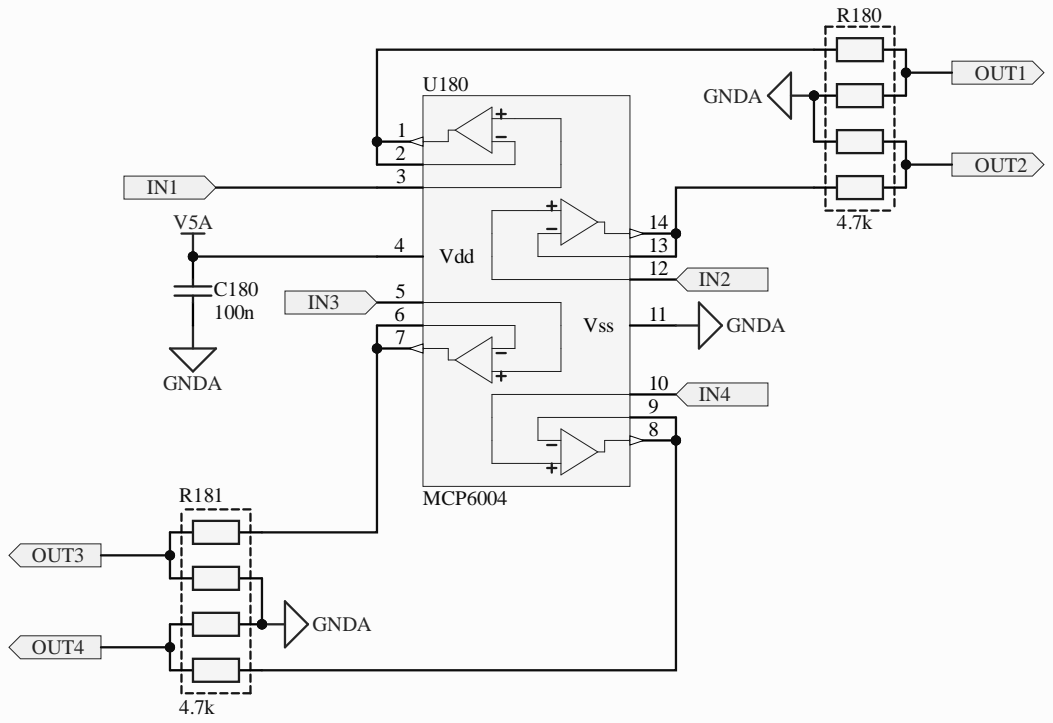
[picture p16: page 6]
Vdd 4; Vss 6; MCP6004; GNDA; OUT1; OUT2; OUT3; OUT4

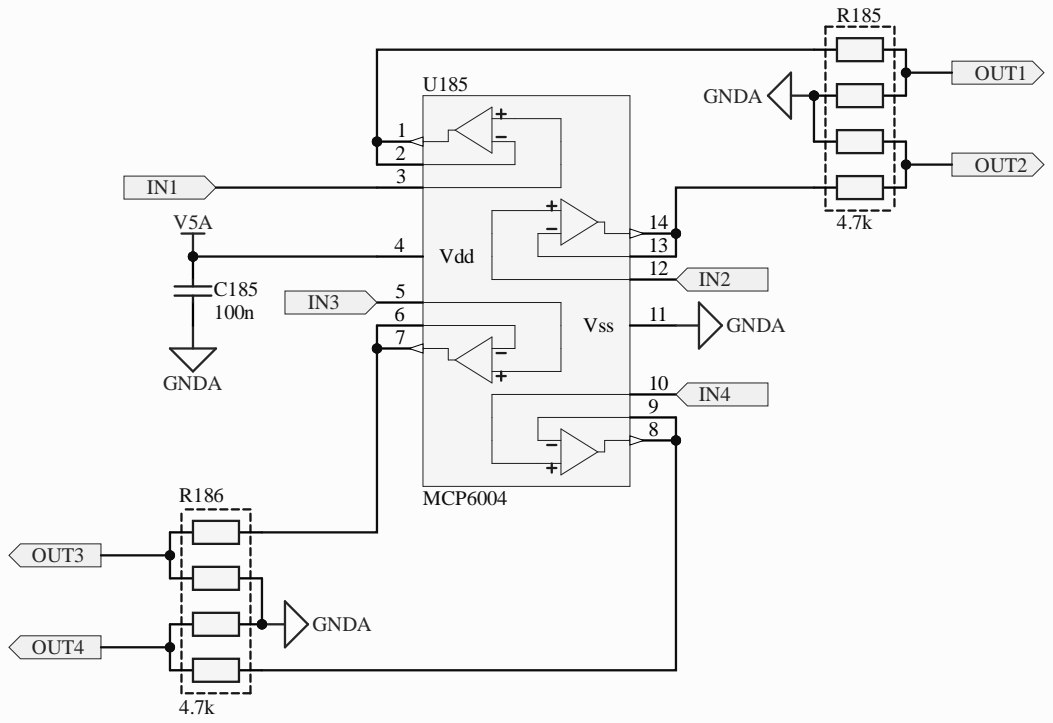
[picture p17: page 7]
Vdd 4; Vss 6; MCP6004; GNDA; OUT1; OUT2; OUT3; OUT4

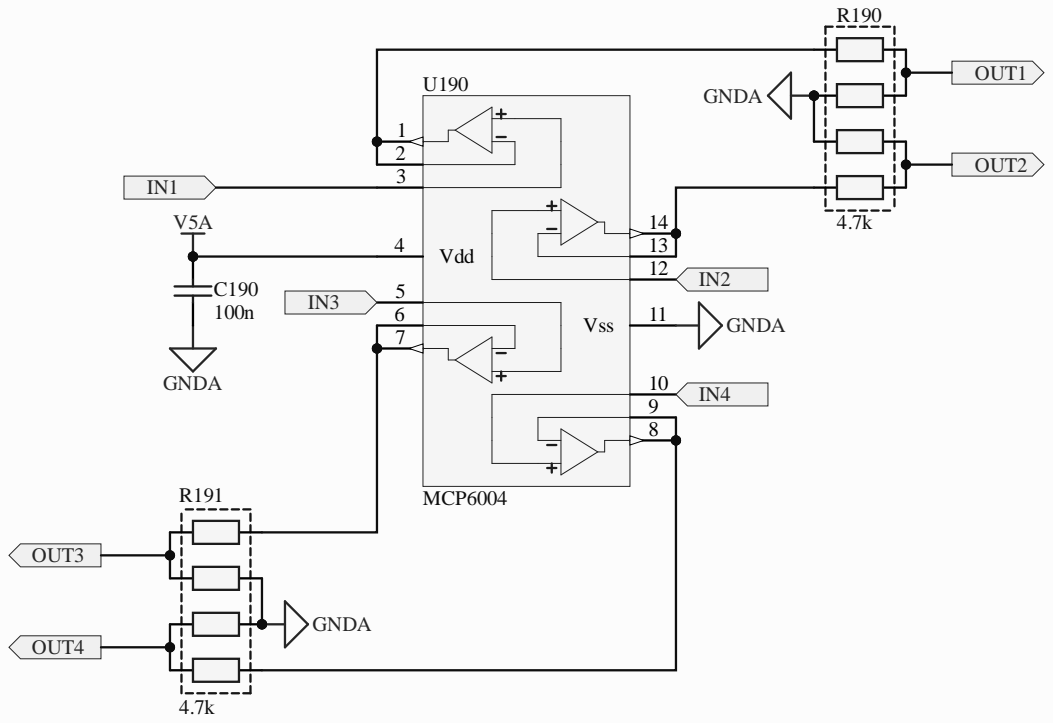
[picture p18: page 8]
Vdd 4; Vss 6; MCP6004; GNDA; OUT1; OUT2; OUT3; OUT4; C190 PIC19001 100n; PIC19002 COC3; PIR19001; PIR19002; PIR19003; PIR19004; PIR19005; PIR19006; PIR19007; PIR19008; COR5; PIR19101; PIR19102; PIR19103; PIR19105; PIR19104; PIR19106; PIR19107; PIR19108; COR6; PIU19001; PIU19002; PIU19003; PIU19004; PIU19005; PIU19006; PIU19007; PIU19008; PIU19009; PIU190010; PIU190011; PIU190012; PIU190013; PIU190014; COU2; PIC19001; POOUT2; POOUT1; POOUT3; POOUT4; POIN1; POIN3 PIU19005; PIU190010 POIN4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

SPI_; VCC; 5 SPI_SCK; 7 SPI_O; lex MicroSD; _MIS


R143 populated: analog input O2S
R145 populated: WAKEUP by CAN

*VIGN input is unprotected!
*A21 is duplicated for ADC and EINT


See pullups replacement file for actual values


# See pullups replacement file for actual values


0 PESD; VCC; 5 RXD; 6 CANH

VRE; _CRA; _CLT; IAT; _IAT; VIG; nRes; VBAT; SWCL; SPI2; _MIS; SPI3; I2C_SCL; SPI1; PWR_; GRE; u mcu.Sch; _IGN; 8.Sch; _can can.Sch; d.Sch; nRS; USB_; P USB_; USBI; A I2C_SCL UART8_RX UART8_TX UART2_RX UART2_TX; N VBAT; VCC; ACC_SC; ACC_; ACC_MIS; ACC_MO; BARO; sen; ors.Sc; LVC1; VBU; wer.Sch; USBID (PA; USBM (PA; USBP (PA; 8 SWDIO (PA13); N5 SWCLK (PA14); N6 nReset; _SCK (PC1; _MISO (PC1; _MOSI (PC1; I2C_SCL (PB1; 3 I2C_SDA (PB11); E4 UART2_TX (PD5); _SCK; _MISO (PB1; _MOSI (PB1; _PWM2 (PC6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

USBM USBP USBID VBUS
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

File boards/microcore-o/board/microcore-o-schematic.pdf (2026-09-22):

# ANALOG V12_RAW

# OUT1 OUT2 OUT3 OUT4

F Date: 2026-09-22; Size: A3; Rev: O; CAM; MCU_CAM; HALL OUT1 OUT2 OUT3; TPS MAP; CLT IAT AN1; MCU_TPS MCU_MAP MCU_CLT MCU_IAT MCU_AN1 MCU_AN2; INJ4; HALL_EN; E2 OUT; GND G; VR-/HALL W1; VR+ W2 Module-vr-max9924-0.3 M3; VBAT; VIGN; E6 GND S1; V12_PERM V1; IN_VIGN V2; V12_RAW V3; V4 Module-power_12and5V-0.3 M2; uSD card and accelerometer on SPI1 bus; Barometer on this I2C bus F40x does not have UART8; Internal TC2030; connector Connected; Connected; Internal buttons Connected V5A_SWITCHABLE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

AMPSEAL pins 8/9/10: FP / Idle / Boost (rev o) Q5-Q7 NCE4080K + gate R5-R7 12 ohm

PCB basename: microcore (no dashes/underscores)
Firmware board: coreefi_micro — needs F407 target later; fw not in this repo
Core EFI rev o: NCE4080K Q1-Q7; LS Q5-Q7 restored; F407VGT6 stays

Sheet: /
File: microcore.kicad_sch
Title: Micro Core
KiCad E.D.A. 10.0.6

Micro Core rev O MCU mega-mcu100/0.3 STM32F407VGT6 (not mega-mcu64) + power_12and5V/0.3 + vr-max9924/0.3 USB Mini-B + TE 776231-1 AMPSEAL; pins 8/9/10 FP / Idle / Boost Sheets: INJ4 (Q1-Q4) LS3 (Q5-Q7) ANALOG HALL Power FETs NCE4080K C191380. coreefi_micro needs F407 target later

# SMAJ33A K

A 2 D5


NCE4080K TO-252-2L (LCSC C191380) on microcore-fp:DPAK
SMAJ33A (DO-214AC) + US1M UF flyback kept 2x12 ohm high-Z per channel (gate R1-R4 + ballast R8-R11) D1-D8 stay on B.Cu beside AMPSEAL J1 D4 US1M

Core EFI rev o: Q1-Q4 NCE4080K C191380; D1-D8 and R8-R11 kept R312

D Date: 2026-09-22; Size: A4; Rev: O; 3 Q5 NCE4080K; 3 Q7 NCE4080K; GND; 3 Q6 NCE4080K; IN1 OUT3 OUT2; IN2 OUT1

LS3 Low-side rev O
NCE4080K TO-252-2L (LCSC C191380) on microcore-fp:DPAK
12 ohm gate; no flyback/TVS (injectors only, same as pre-rev-n) Discrete MOSFET, not a protected smart FET. RDS(on) rated at Vgs=10 V; MCU gate is 3.3 V.

no flyback/TVS on LS; not a protected smart FET R512

Core EFI rev o: NCE4080K TO-252-2L LCSC C191380; gate 12 ohm

Sheet: /LS3/
File: LS3.kicad_sch
Title: LS3 Low-side
KiCad E.D.A. 10.0.6

D Date: 2026-09-13; KiCad E.D.A. 10.0.6; Size: A4; Rev: B; Title: ANALOG; File: ANALOG.kicad_sch; Sheet: /ANALOG/; Core EFI; MCU_MAP; TPS; IAT CLT MAP; MCU_AN2 MCU_AN1 MCU_IAT MCU_CLT MCU_TPS

ANALOG input conditioning stub Pull-ups / dividers / ESD TBD — passthrough hierarchy for pin map

D Date: 2026-09-13; KiCad E.D.A. 10.0.6; Size: A4; Rev: B; Title: HALL; File: HALL.kicad_sch; Sheet: /HALL/; Core EFI; CAM; MCU_CAM

HALL input conditioning stub Pull-ups / dividers / ESD TBD — passthrough hierarchy for pin map

Vdd 4; Vss 6; MCP6004; GNDA; OUT1; OUT2; OUT3; OUT4

Vdd 4; Vss 6; MCP6004; GNDA; OUT1; OUT2; OUT3; OUT4

Vdd 4; Vss 6; MCP6004; GNDA; OUT1; OUT2; OUT3; OUT4; C190 PIC19001 100n; PIC19002 COC3; PIR19001; PIR19002; PIR19003; PIR19004; PIR19005; PIR19006; PIR19007; PIR19008; COR5; PIR19101; PIR19102; PIR19103; PIR19105; PIR19104; PIR19106; PIR19107; PIR19108; COR6; PIU19001; PIU19002; PIU19003; PIU19004; PIU19005; PIU19006; PIU19007; PIU19008; PIU19009; PIU190010; PIU190011; PIU190012; PIU190013; PIU190014; COU2; PIC19001; POOUT2; POOUT1; POOUT3; POOUT4; POIN1; POIN3 PIU19005; PIU190010 POIN4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

SPI_; VCC; 5 SPI_SCK; 7 SPI_O; lex MicroSD; _MIS


R143 populated: analog input O2S
R145 populated: WAKEUP by CAN

*VIGN input is unprotected!
*A21 is duplicated for ADC and EINT


See pullups replacement file for actual values


# See pullups replacement file for actual values


0 PESD; VCC; 5 RXD; 6 CANH

VRE; _CRA; _CLT; IAT; _IAT; VIG; nRes; VBAT; SWCL; SPI2; _MIS; SPI3; I2C_SCL; SPI1; PWR_; GRE; u mcu.Sch; _IGN; 8.Sch; _can can.Sch; d.Sch; nRS; USB_; P USB_; USBI; A I2C_SCL UART8_RX UART8_TX UART2_RX UART2_TX; N VBAT; VCC; ACC_SC; ACC_; ACC_MIS; ACC_MO; BARO; sen; ors.Sc; LVC1; VBU; wer.Sch; USBID (PA; USBM (PA; USBP (PA; 8 SWDIO (PA13); N5 SWCLK (PA14); N6 nReset; _SCK (PC1; _MISO (PC1; _MOSI (PC1; I2C_SCL (PB1; 3 I2C_SDA (PB11); E4 UART2_TX (PD5); _SCK; _MISO (PB1; _MOSI (PB1; _PWM2 (PC6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

USBM USBP USBID VBUS
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

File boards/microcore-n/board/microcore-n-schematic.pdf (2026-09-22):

# HALL V12_RAW

# OUT1 OUT2 OUT3 OUT4

F Date: 2026-09-22; Size: A3; Rev: N; TPS MAP; CLT IAT AN1; MCU_TPS MCU_MAP MCU_CLT MCU_IAT MCU_AN1 MCU_AN2; ANALOG; CAM; MCU_CAM; INJ4; uSD card and accelerometer on SPI1 bus; Barometer on this I2C bus F40x does not have UART8; Internal TC2030; connector Connected; Connected; Internal buttons Connected V5A_SWITCHABLE; E1 GNDA; I2C_SCL_(PB10); E3 I2C_SDA_(PB11); IN_VIGN_(PA5) E5; SPI2_CS_/_CAN2_RX_(PB12); SPI2_SCK_/_CAN2_TX_(PB13); SPI2_MISO_(PB14); SPI2_MOSI_(PB15); E9 OUT_INJ8_(PD12) E10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

unstuffed LS — future option (rev n) Q5-Q7 and R5-R7 removed Module-power_12and5V-0.3 M2

AMPSEAL pins 8/9/10 reserved / NC

PCB basename: microcore (no dashes/underscores)
Firmware board: coreefi_micro — needs F407 target later; fw not in this repo
Core EFI rev n cost-down: F407VGT6 on mega-mcu100; LS Q5-Q7 removed

Sheet: /
File: microcore.kicad_sch
Title: Micro Core
KiCad E.D.A. 10.0.6

Micro Core rev N — cost-down MCU mega-mcu100/0.3 STM32F407VGT6 (not mega-mcu64) + power_12and5V/0.3 + vr-max9924/0.3 USB Mini-B + TE 776231-1 AMPSEAL; pins 8/9/10 reserved / NC

Sheets: INJ4 (Q1-Q4) LS3-NC stub ANALOG HALL Firmware: coreefi_micro needs F407 target later

SMAJ33A GND | R912 R812 K | 1 A 2 D4 US1M
rev K: D1-D8 on B.Cu beside AMPSEAL J1 D4 US1MK | 1 A 2 GND


INJ4 Injectors DPAK N-FET + SMAJ33A (DO-214AC) + US1M UF flyback 2x12 ohm high-Z per channel (gate R1-R4 + ballast R8-R11)

1 | 2 | 3 | 4 | 5 | 6
1 | 2 | 3 | 4 | 5 | 6

AB

C

D

AB

C

D Date: 2026-09-22

KiCad E.D.A. 10.0.6

Size: A4 | Rev: N Id: 3/5

## Title: LS3 Low-side

File: LS3.kicad_sch

Sheet: /LS3-NC/

Core EFI rev n cost-down stub: Q5-Q7 and R5-R7 removed

AMPSEAL pins 8/9/10 reserved / NC (unstuffed LS, future option)

LS3 stub — rev n cost-down Q5 (FP), Q6 (idle), Q7 (boost) and gate resistors R5-R7 are removed. No DPAK, no tracks. AMPSEAL pins 8/9/10 are reserved / NC.

Injector stage Q1-Q4 + R1-R4 + R8-R11 + D1-D8 stays on INJ4. Future option: restuff LS on a later rev; do not leave copper to these FETs.

D Date: 2026-09-13; KiCad E.D.A. 10.0.6; Size: A4; Rev: B; Title: ANALOG; File: ANALOG.kicad_sch; Sheet: /ANALOG/; Core EFI; MCU_MAP; TPS; IAT CLT MAP; MCU_AN2 MCU_AN1 MCU_IAT MCU_CLT MCU_TPS

ANALOG input conditioning stub Pull-ups / dividers / ESD TBD — passthrough hierarchy for pin map

D Date: 2026-09-13; KiCad E.D.A. 10.0.6; Size: A4; Rev: B; Title: HALL; File: HALL.kicad_sch; Sheet: /HALL/; Core EFI; CAM; MCU_CAM

HALL input conditioning stub Pull-ups / dividers / ESD TBD — passthrough hierarchy for pin map

Vdd 4; Vss 6; MCP6004; GNDA; OUT1; OUT2; OUT3; OUT4

Vdd 4; Vss 6; MCP6004; GNDA; OUT1; OUT2; OUT3; OUT4

Vdd 4; Vss 6; MCP6004; GNDA; OUT1; OUT2; OUT3; OUT4; C190 PIC19001 100n; PIC19002 COC3; PIR19001; PIR19002; PIR19003; PIR19004; PIR19005; PIR19006; PIR19007; PIR19008; COR5; PIR19101; PIR19102; PIR19103; PIR19105; PIR19104; PIR19106; PIR19107; PIR19108; COR6; PIU19001; PIU19002; PIU19003; PIU19004; PIU19005; PIU19006; PIU19007; PIU19008; PIU19009; PIU190010; PIU190011; PIU190012; PIU190013; PIU190014; COU2; PIC19001; POOUT2; POOUT1; POOUT3; POOUT4; POIN1; POIN3 PIU19005; PIU190010 POIN4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

SPI_; VCC; 5 SPI_SCK; 7 SPI_O; lex MicroSD; _MIS


R143 populated: analog input O2S
R145 populated: WAKEUP by CAN

*VIGN input is unprotected!
*A21 is duplicated for ADC and EINT


See pullups replacement file for actual values


# See pullups replacement file for actual values


0 PESD; VCC; 5 RXD; 6 CANH

VRE; _CRA; _CLT; IAT; _IAT; VIG; nRes; VBAT; SWCL; SPI2; _MIS; SPI3; I2C_SCL; SPI1; PWR_; GRE; u mcu.Sch; _IGN; 8.Sch; _can can.Sch; d.Sch; nRS; USB_; P USB_; USBI; A I2C_SCL UART8_RX UART8_TX UART2_RX UART2_TX; N VBAT; VCC; ACC_SC; ACC_; ACC_MIS; ACC_MO; BARO; sen; ors.Sc; LVC1; VBU; wer.Sch; USBID (PA; USBM (PA; USBP (PA; 8 SWDIO (PA13); N5 SWCLK (PA14); N6 nReset; _SCK (PC1; _MISO (PC1; _MOSI (PC1; I2C_SCL (PB1; 3 I2C_SDA (PB11); E4 UART2_TX (PD5); _SCK; _MISO (PB1; _MOSI (PB1; _PWM2 (PC6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

USBM USBP USBID VBUS
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

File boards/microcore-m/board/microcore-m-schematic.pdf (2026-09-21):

# OUT1 OUT2 OUT3 OUT4

# INJ4 CAM MCU_CAM

F Date: 2026-09-15; Size: A3; Rev: E; HALL; CLT IAT AN1; MCU_TPS MCU_MAP MCU_CLT MCU_IAT MCU_AN1 MCU_AN2; ANALOG OUT1 OUT2 OUT3; uSD card and accelerometer on SPI1 bus; Barometer on this I2C bus F40x does not have UART8; Internal TC2030; connector Connected; Connected; Internal buttons Connected V5A_SWITCHABLE; E1 GNDA; I2C_SCL_(PB10); E3 I2C_SDA_(PB11); IN_VIGN_(PA5) E5; SPI2_CS_/_CAN2_RX_(PB12); SPI2_SCK_/_CAN2_TX_(PB13); SPI2_MISO_(PB14); SPI2_MOSI_(PB15); E9 OUT_INJ8_(PD12) E10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

IGN8 V12_RAW
PCB basename: microcore (no dashes/underscores) V12_RAW

TPS MAP
IAT CLT CLT

nReset BOOT0 Micro Core rev E — modules-v1 nest+route MCU mega-mcu100/0.3 + power_12and5V/0.3 + vr-max9924/0.3 USB Mini-B + TE 776231-1 AMPSEAL (frame SW_BOOT/SW_RESET removed rev K) Sheets: INJ4 LS3 ANALOG HALL (DPAK frame) Firmware: coreefi_micro

Firmware board: coreefi_micro
modules-v1 rev E — nest DPAKs + frame routing + GND pours
Core EFI
Sheet: /
File: microcore.kicad_sch
Title: Micro Core
KiCad E.D.A. 10.0.6

SMAJ33A GND | R912 R812 K | 1 A 2 D4 US1M
rev K: D1-D8 on B.Cu beside AMPSEAL J1 D4 US1MK | 1 A 2 GND


INJ4 Injectors DPAK N-FET + SMAJ33A (DO-214AC) + US1M UF flyback 2x12 ohm high-Z per channel (gate R1-R4 + ballast R8-R11)

# VND14NV04-E GND

D Date: 2026-09-13; Size: A4; Rev: B; 3 Q5 VND14NV04-E; 3 Q6 VND14NV04-E GND; GND; IN2 OUT3; IN3 OUT2 OUT1

LS3 Low-side DPAK N-FET drivers (alphax LS style) 12 ohm gate; flyback/TVS not in SPEC power-stage (injectors only)

INJ4 rev J has SMAJ33A + US1M + 2x12 ohm high-Z

Core EFI
Sheet: /LS3/
File: LS3.kicad_sch
Title: LS3 Low-side
KiCad E.D.A. 10.0.6

D Date: 2026-09-13; KiCad E.D.A. 10.0.6; Size: A4; Rev: B; Title: ANALOG; File: ANALOG.kicad_sch; Sheet: /ANALOG/; Core EFI; MCU_MAP; TPS; IAT CLT MAP; MCU_AN2 MCU_AN1 MCU_IAT MCU_CLT MCU_TPS

ANALOG input conditioning stub Pull-ups / dividers / ESD TBD — passthrough hierarchy for pin map

D Date: 2026-09-13; KiCad E.D.A. 10.0.6; Size: A4; Rev: B; Title: HALL; File: HALL.kicad_sch; Sheet: /HALL/; Core EFI; CAM; MCU_CAM

HALL input conditioning stub Pull-ups / dividers / ESD TBD — passthrough hierarchy for pin map

Vdd 4; Vss 6; MCP6004; GNDA; OUT1; OUT2; OUT3; OUT4
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

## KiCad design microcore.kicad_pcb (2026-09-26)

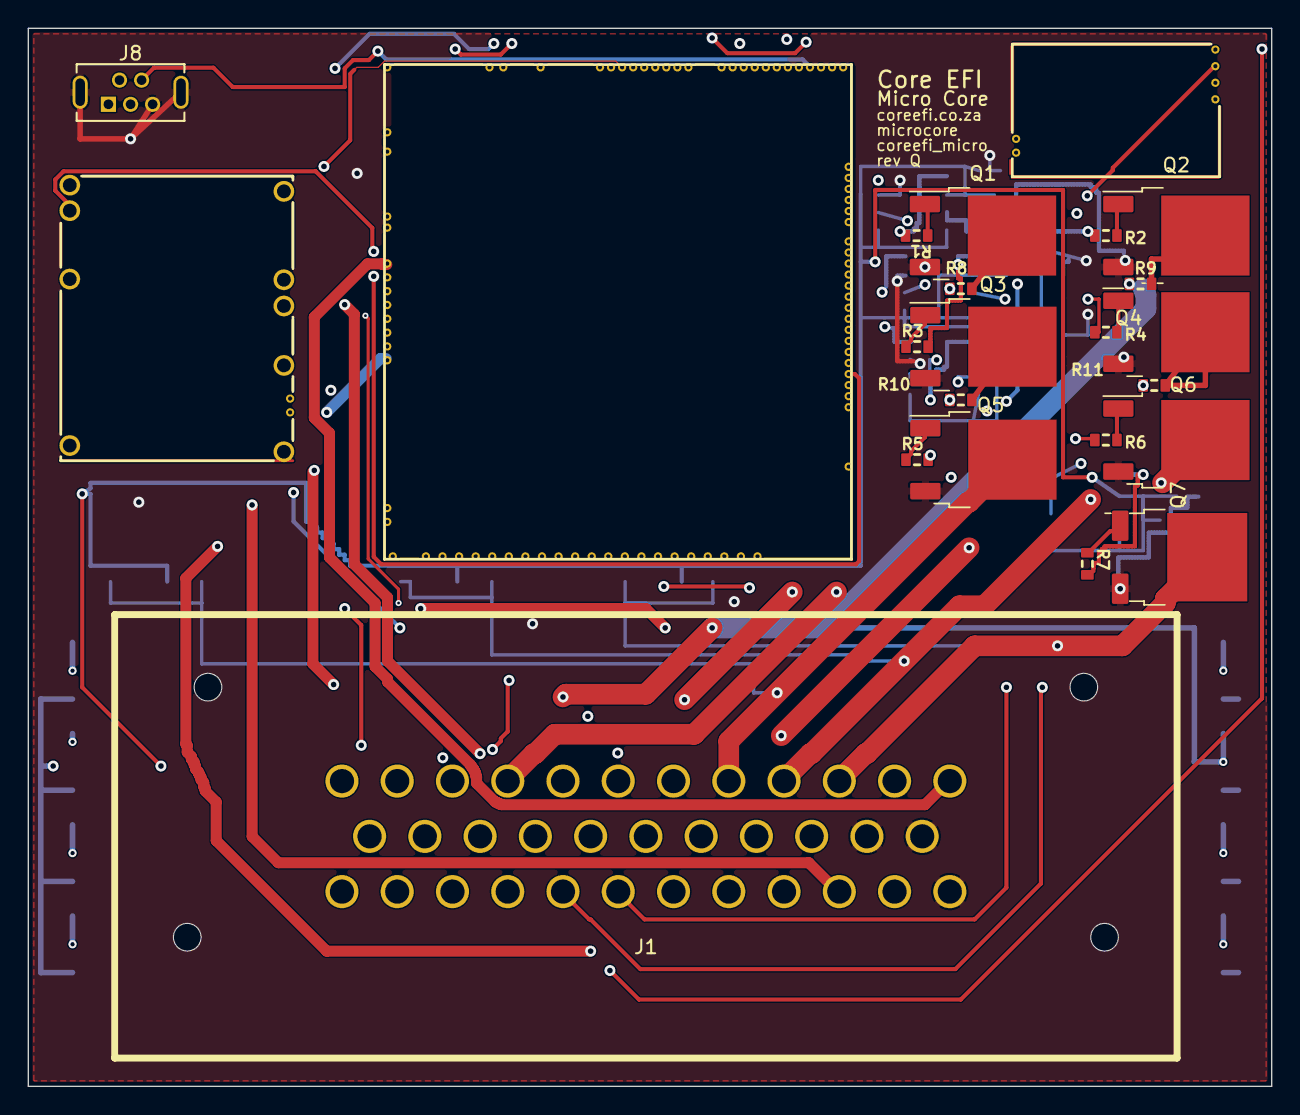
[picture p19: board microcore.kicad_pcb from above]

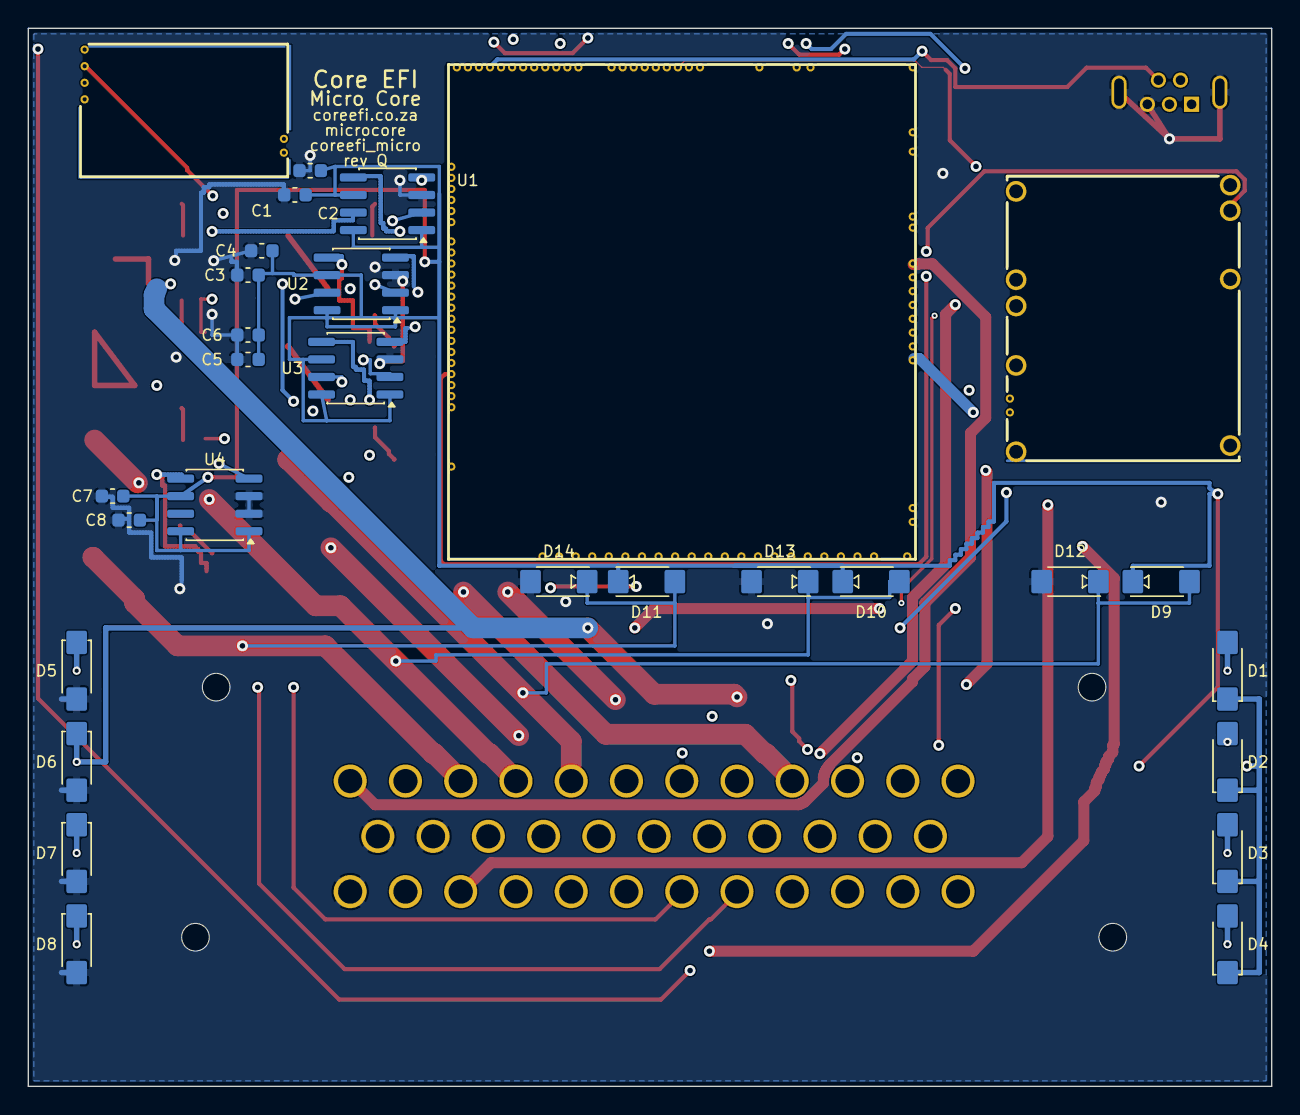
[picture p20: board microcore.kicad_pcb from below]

Board: 4 copper layers, 90.0 x 76.6 mm, 49 parts (26 on the bottom side), 64 nets.

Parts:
C1, C3, C5, C7: 100n; C0603
C2, C4, C6, C8: 1u; C0603
D1, D2, D3, D4, D9, D10, D11: US1M; DO214AC
D5, D6, D7, D8, D12, D13, D14: SMAJ33A; DO214AC
J1: TE_776231-1; TE_776231
J8: USB_B_Mini; USB-MINI-B-VERTICAL
M1: Module:mega-mcu100/0.3; mega-mcu100
M2: Module-power_12and5V-0.3; power_12and5V
M3: Module-vr-max9924-0.3; vr-max9924
Q1, Q2, Q3, Q4, Q5, Q6, Q7: NCE4080K; DPAK
R1, R2, R3, R4, R5, R6, R7, R8, R9, R10, R11: 12; R0603
U1, U2, U3, U4: SLM27524CA-DG; SOIC-8

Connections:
/AN1: J1.19, M1.S9 (IN_AUX1_(PB0))
/AN2: J1.21, M1.S8 (IN_AUX2_(PC4/PE9))
/CAN_H: J1.2, M1.W11 (CANH)
/CAN_L: J1.3, M1.W12 (CANL)
/CLT: J1.24, M1.S21 (IN_CLT_(PC2))
/DIN1: J1.11, M1.S4 (IN_D1_(PE12))
/DIN2: J1.26, M1.S3 (IN_D2_(PE13))
/HALL_CAM: J1.27, M1.S16 (IN_CAM_(PA6))
/IAT: J1.25, M1.S20 (IN_IAT_(PC3))
/IGN1: J1.12, M1.W10 (IGN1_(PC13))
/IGN2: J1.13, M1.W9 (IGN2_(PE5))
/IGN3: J1.14, M1.W8 (IGN3_(PE4))
/IGN4: J1.15, M1.W7 (IGN4_(PE3))
/IGN5: J1.30, M1.W6 (IGN5_(PE2))
/IGN6: J1.31, M1.W5 (IGN6_(PB8))
/IGN7: J1.32, M1.W4 (IGN7_(PB9))
/IGN8: J1.33, M1.W3 (IGN8_(PE6))
/INJ1: D1.2, D5.1, J1.4, R8.1
/INJ2: D2.2, D6.1, J1.5, R9.1
/INJ3: D3.2, D7.1, J1.6, R10.1
/INJ4: D4.2, D8.1, J1.7, R11.1
/LS1_FP: D9.2, D12.1, J1.8, Q5.2
/LS2_IDLE: D10.2, D13.1, J1.9, Q6.2
/LS3_BOOST: D11.2, D14.1, J1.10, Q7.2
/MAP: J1.18, M1.S13 (IN_MAP1_(PC0))
/OUT_INJ1: M1.E17 (OUT_INJ1_(PD3)), U1.4
/OUT_INJ2: M1.E16 (OUT_INJ2_(PA9)), U1.2
/OUT_INJ3: M1.E15 (OUT_INJ3_(PD11)), U2.4
/OUT_INJ4: M1.E14 (OUT_INJ4_(PD10)), U2.2
/OUT_LS1: M1.E18 (OUT_PWM1_(PD13)), U3.4
/OUT_LS2: M1.E19 (OUT_PWM2_(PC6)), U3.2
/OUT_LS3: M1.E20 (OUT_PWM3_(PC7)), U4.4
/SGND: J1.20, J1.34, M1.E2 (GNDA), M1.W1 (GNDA)
/TPS: J1.17, M1.S18 (IN_TPS_(PA4))
/USBID_(PA10): J8.4, M1.N4 (USBID_(PA10))
/USBM_(PA11): J8.2, M1.N2 (USBM_(PA11))
/USBP_(PA12): J8.3, M1.N3 (USBP_(PA12))
/V5_REF: J1.16, M2.E4 (V5), M3.E4 (V5_IN)
/V12_RAW: C1.2, C2.2, C3.2, C4.2, C5.2, C6.2, C7.2, C8.2, D1.1, D2.1, D3.1, D4.1, D9.1, D10.1, D11.1, J1.1, M2.V3 (V12_RAW), U1.1, U1.6, U1.8, U2.1, U2.6, U2.8, U3.1, U3.6, U3.8, U4.1, U4.6, U4.8
/VBAT: M1.N17 (VBAT), M2.E1 (VBAT)
/VBUS: J8.1, M1.N1 (VBUS)
/VIGN_SENSE: M1.E5 (IN_VIGN_(PA5)), M2.V2 (IN_VIGN)
/VR_N: J1.29, M3.W1 (VR-)
/VR_OUT: M1.S14 (IN_CRANK_(PB1)), M3.E3 (OUT)
/VR_P: J1.28, M3.W2 (VR+)
GND: C1.1, C2.1, C3.1, C4.1, C5.1, C6.1, C7.1, C8.1, D5.2, D6.2, D7.2, D8.2, D12.2, D13.2, D14.2, J1.22, J1.23, J1.35, J8.5, J8.6, M1.G (GND), M2.S1 (GND), M3.G (GND), Q1.3, Q2.3, Q3.3, Q4.3, Q5.3, Q6.3, Q7.3, U1.3, U2.3, U3.3, U4.2, U4.3
unnamed: Q1.2, R8.2
unnamed: Q1.1, R1.1
unnamed: Q2.2, R9.2
unnamed: Q2.1, R2.1
unnamed: Q3.2, R10.2
unnamed: Q3.1, R3.1
unnamed: Q4.2, R11.2
unnamed: Q4.1, R4.1
unnamed: Q5.1, R5.1
unnamed: Q6.1, R6.1
unnamed: Q7.1, R7.1
unnamed: R2.2, U1.7
unnamed: R1.2, U1.5
unnamed: R4.2, U2.7
unnamed: R3.2, U2.5
unnamed: R6.2, U3.7
unnamed: R5.2, U3.5
unnamed: R7.2, U4.5

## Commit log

2026-09-13 Import Hellen-One Create Board scaffolding for Micro Core
    Add hellen-example workflows, hellen-one + kicad6-libraries submodules,
    revision.txt (micro+core → microcore), bom_replace, lib tables, and a
    minimal frame PCB/schematic with aux_axis_origin and bottom-left origin.
    Preserve SPEC/README; document Hellen FAQ tips under docs/.
    [bom_replace_microcore-a.csv, microcore.kicad_pcb, microcore.kicad_sch]
2026-09-13 Fix KiCad PCB text justify for Create Board CI
    KiCad 10 rejects (justify center) on gr_text; use left bottom like other Hellen boards.
    [microcore.kicad_pcb]
2026-09-13 Give scaffold PCB copper so Create Board preview can render
    Empty boards fail Hellen PNG render (cairo write error). Add an F.Cu fill and a via; keep boards/.gitkeep for fab output path.
    [microcore.kicad_pcb]
2026-09-13 [skip actions] Auto-generated board v2.1
    [microcore-B_Cu.gbl, microcore-B_Mask.gbs, microcore-B_Paste.gbp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]
2026-09-13 Add first real Micro Core modules (rev b)
    Place mega-mcu100/0.3, power_12and5V/0.3, vr-discrete/0.5 and TE 776231-1
    on the 90x60 frame; add INJ4/LS3/ANALOG/HALL hierarchy with DPAK drivers.
    Bump BOARD_REVISION to b so Create Board writes boards/microcore-b/.
    [ANALOG.kicad_sch, HALL.kicad_sch, INJ4.kicad_sch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]
2026-09-13 Fix PCB gr_text justify for KiCad 10 Create Board
    KiCad 10 rejects (justify center); use left top like prior scaffold fix.
    [microcore.kicad_pcb]
2026-09-13 Set aux_axis_origin to board bottom-left (0,60)
    KiCad place export Y-flips about aux origin; with aux at 0,0 module
    CPL Y went negative and gerbmerge trim crashed. Match Hellen boards:
    aux at Edge.Cuts bottom-left so place Y stays >= 0.
    [microcore.kicad_pcb]
2026-09-13 Inset module footprints; drop frame DPAKs for gerbmerge
    Keep mega/power/VR + AMPSEAL on PCB with margin from Edge.Cuts so
    rectangular pad trim does not hit gerbmerge float&int bug. DPAKs remain
    on INJ4/LS3 schematics for the next placement pass.
    [microcore.kicad_pcb]
2026-09-14 Swap VR to max9924/0.3; add frame USB Mini-B; bump rev c
    Replace vr-discrete/0.5 with vr-max9924/0.3 (east of MCU), keep VR± on
    AMPSEAL 28/29. Add hellen-one-common USB_B_Mini (USB-MINI-B-VERTICAL) on
    the north edge wired to mega-mcu100 USBM/USBP/USBID + VBUS/GND. Bump
    BOARD_REVISION to c after Create Board already produced rev b on this branch.
    [bom_replace_microcore-c.csv, microcore.kicad_pcb, microcore.kicad_sch]
2026-09-14 Fix microcore.kicad_sch load for KiCad CLI (escaped text newlines)
    Literal newlines inside the rev-C (text ...) string made kicad-cli
    fail with "Failed to load schematic". Use \n escapes like the prior
    rev-B note, and refresh USB_B_Mini embedding from uaefi.
    [microcore.kicad_sch]
2026-09-14 Point hellen-one at fork with vr-max9924 BOM comment fix
    Create Board BOM merge failed: C72043 comment GREEN (vr-max9924/0.3)
    vs LED-GREEN-0603 (mega-mcu100). Use forked hellen-one with aligned
    comment so process_BOM can merge duplicates.
    [bom_replace_microcore-c.csv]
2026-09-15 Fix schematic open on older KiCad: drop embedded_fonts
    KiCad 8 rejects (embedded_fonts no) after sheet_instances, which blocked
    opening microcore.kicad_sch and the frame sheets.
    [ANALOG.kicad_sch, HALL.kicad_sch, INJ4.kicad_sch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]
2026-09-15 Vendor DPAK/R0603 footprints for Update PCB without submodule gaps
    Frame inj/LS sheets now use microcore-fp (in-repo footprints/) so KiCad
    finds DPAK and R0603 even when hellen-one-common is missing from a zip
    checkout. Keep hellen-one-common for Mini-B and other shared parts.
    [INJ4.kicad_sch, LS3.kicad_sch]
2026-09-15 Fix top schematic wiring so labels connect to Hellen module pins
    [INJ4.kicad_sch, LS3.kicad_sch, microcore.kicad_sch]
2026-09-15 Freeze AMPSEAL spare pins and add frame BOOT/RESET (rev d)
    Assign pins 11/26/30–35 to DIN1–2, IGN5–8, SGND, PGND; wire to mega.
    Add gasketed SW_BOOT (BOOT0–V33) and SW_RESET (nReset–GND) near USB.
    [bom_replace_microcore-d.csv, microcore.kicad_pcb, microcore.kicad_sch]
2026-09-15 Align frame button BOM comment with mega BTN (C115357)
    Create Board failed: Comment mismatch for C115357 Button_SPST vs BTN.
    [bom_replace_microcore-d.csv, microcore.kicad_pcb, microcore.kicad_sch]
2026-09-15 Use ASCII-only comments in bom_replace for Hellen BOM tool
    En-dashes in bom_replace_microcore-d.csv aborted Create Board.
    [bom_replace_microcore-d.csv]
2026-09-15 Rev e: nest INJ/LS DPAKs on frame, apply netlist, GND pours, route
    Place Q1-Q7 + R1-R7 clear of AMPSEAL keepout; unify GND global net;
    assign schematic nets to pads; add F/B GND zones and scripted frame
    tracks/vias. Module copper remains Create Board gerber merge.
    [ANALOG.kicad_sch, HALL.kicad_sch, bom_replace_microcore-e.csv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]
2026-09-15 Fix Create Board: drop GND zones that break gerbmerge trim
    gerbmerge rectCenter crashes on float extents from zone polygons
    (TypeError: float & int). Keep scripted frame tracks/vias; pours later.
    [bom_replace_microcore-e.csv, microcore.kicad_pcb]
2026-09-15 Bump hellen-one: gerbmerge float-safe rectCenter for Create Board
    Unblocks gerbmerge trim on KiCad metric clipped rectangular flashes
    (DPAK tabs / edge pads) used by rev e frame nesting.
2026-09-16 Rev f: clear AMPSEAL silk keepout for DPAKs
    Re-nest Q1–Q6 to y=15/22/29 (left x=68, right x=82) with gate Rs
    clear of drain pads; move Q7+R7 into M2–M1 corridor (Q7 rot 90);
    jog IGN2 around Q7; rebuild FET tracks/vias. Nothing in J1 silk
    keepout (y≥35). Bump BOARD_REVISION to f.
    [bom_replace_microcore-f.csv, microcore.kicad_pcb]
2026-09-16 Fix bom_replace-f: ASCII-only comments for Hellen BOM tool
    [bom_replace_microcore-f.csv]
2026-09-16 Rev g: add F.Cu and B.Cu GND copper pours
    Board-interior GND zones (0.4 mm inset, clearance 0.2, thermal
    0.25/0.3) on F.Cu and B.Cu only; filled via pcbnew. SGND left
    separate. AMPSEAL keepout positions unchanged. ASCII bom_replace-g.
    [bom_replace_microcore-g.csv, microcore.kicad_pcb]
2026-09-16 docs: hardware status rev g, Boss brief, README paths
    Commit MICROCORE_BRIEF.md, add HARDWARE_STATUS_rev_g.md with fab leftovers
    and DRC summary, and point README at boards/microcore-g (drop stale freeze).
2026-09-20 Bump Microcore board revision g → h after KiCad update
    [bom_replace_microcore-h.csv]
2026-09-20 Fix drill origin to Edge.Cuts bottom-left so create-board HTML BOM can parse rev h
    [microcore.kicad_pcb]
2026-09-21 Restore microcore.kicad_pcb and set drill origin to Edge.Cuts bottom-left (rev h)
    ce63db4 wiped the PCB to ~49 bytes; restore from 298ebd5 and set
    aux/grid origin to Edge.Cuts BL (107.5, 148.0872). Add empty-PCB guard.
    [microcore.kicad_pcb]
2026-09-21 Rev i: J8 GND stitch, FET/gate LCSC, rev-h status (not fab-ready)
    Stitch J8 pads 5/6 to new GND via (clear of VBUS). Assign C155647/C22783
    in bom_replace. Waive frame ANALOG/HALL to mega-module input lite. Document
    KiCad 10 DRC vs rev-g and flyback/TVS layout blocker for Boss.
    [bom_replace_microcore-i.csv, microcore.kicad_pcb]
2026-09-21 docs: note boards/microcore-i Create Board green; hold flyback decision
2026-09-21 Rev j: injector SMAJ33A TVS, US1M flyback, and 2nd 12Ω per INJ channel
    SPEC power-stage protection on INJ4 sch+PCB: R8–R11 ballast, D1–D4 US1M,
    D5–D8 SMAJ33A (DO-214AC equivalent of SMBJ33A). FET cluster left in place;
    new parts in alley + pocket C. BOARD_REVISION bumped to j. PCB remains
    substantial (zones + aux origin intact).
    [INJ4.kicad_sch, LS3.kicad_sch, bom_replace_microcore-j.csv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]
2026-09-21 fix bom_replace-j: ASCII-only comments for Hellen BOM tool
    [bom_replace_microcore-j.csv]
2026-09-21 Rev k: move injector diodes to B.Cu near J1; drop frame buttons
    Flip D1-D4 (US1M) and D5-D8 (SMAJ33A) onto the bottom copper on the
    west/east flanks of AMPSEAL J1, outside the TE_776231 silk/body keepout,
    and delete the old F.Cu alley/pocket-C footprints and 0.4 mm wrap tracks.
    Remove frame SW_BOOT/SW_RESET from schematic and PCB (mega-mcu100
    internal buttons stay). Bump BOARD_REVISION j to k; PCB stays substantial
    with Edge.Cuts drill origin unchanged.
    [INJ4.kicad_sch, bom_replace_microcore-k.csv, microcore.kicad_pcb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]
2026-09-21 Rev l: refill F.Cu+B.Cu GND pours; Core EFI silkscreen
    Refill outer GND zones after the rev-k diode move so fab copper is
    filled (0.4 mm Edge.Cuts inset, 0.2 mm clearance, thermal 0.25/0.3).
    Add ASCII Core EFI branding on F.SilkS and B.SilkS. Not production-ready:
    B.Cu diode collectors still need a human copper pass.
    [bom_replace_microcore-l.csv, microcore.kicad_pcb]
2026-09-21 Rev m: re-route D1-D8 collectors around AMPSEAL
    Delete rev-k B.Cu east-west spines and opposite-pad stubs. Join
    flyback/TVS pads via south-of-J1 In1/In2 buses and B.Cu GND/V12
    spines on true pad Y. Refill F/B GND pours. Silk branding preserved
    as rev M. Not fab-ready (Hellen keepout/padstack + leftover In1
    INJ3/VR_OUT).
    [bom_replace_microcore-m.csv, microcore.kicad_pcb]
2026-09-22 Rev n: F407 on mega-mcu100 and drop LS FETs
    Swap module U105 from STM32F429VIT6 (C92002) to STM32F407VGT6
    (LCSC C12345) in bom_replace_microcore-n.csv. Keep mega-mcu100/0.3.
    Remove Q5-Q7 and gate R5-R7 from the LS3 sheet and the PCB, including
    their tracks and vias. AMPSEAL pins 8/9/10 are reserved / NC.
    [LS3.kicad_sch, bom_replace_microcore-n.csv, microcore.kicad_pcb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]
2026-09-22 Rev n: refill F/B GND pours after LS FET removal
    kicad-cli 10.0.6 DRC with zone refill. Fill polygons update only.
    456 violations (217 error / 239 warning); no LS-net shorts or dangling vias.
    [microcore.kicad_pcb]
2026-09-22 Rev n: note zone refill is already in the board file
    Leftover list no longer asks for a second refill pass.
2026-09-22 Rev o: NCE4080K on Q1-Q7 and restore LS FETs
    Swap every power FET from VND14NV04-E to NCE4080K (LCSC C191380,
    TO-252-2L) on the existing DPAK land. Bring back Q5-Q7 and gate
    R5-R7, and put AMPSEAL pins 8/9/10 back to fuel pump, idle, and boost.
    F407VGT6 on mega-mcu100, injector TVS/flyback, Core EFI silk, GND
    pours, and the drill origin stay. RDS(on) is rated at 10 V; the
    3.3 V gate has no added driver.
    [INJ4.kicad_sch, LS3.kicad_sch, bom_replace_microcore-o.csv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]
2026-09-23 GHA says update kicad6-libraries
2026-09-24 Docs: compare DPAK FETs for 3.3 V gate drive (#8)
    Keep Q1–Q7 on NCE4080K. Record why DMTH4004LK3 is a poor
    swap at 3.3 V, and which TO-252 part is worth a later prototype.
2026-09-25 Rev p: AOD4184A (C99124) + LS US1M/SMAJ33A + DRC (#9)
    * Rev p: AOD4184A on Q1-Q7, LS flyback+TVS, frame short fixes
    Quintin chose AOD4184A (LCSC C99124) plus TVS for budget and reliability.
    Q5-Q7 get the existing US1M flyback and SMAJ33A. Injector/VR frame shorts
    on the board copper are cleared; Hellen module pad-G noise stays documented.
    * Rev p: keep Q1-Q7 as NCE4080K; LS US1M+SMAJ33A stays
    Budget and reliability first. No FET or BOM upgrade and no DPAK land change. Low-side clamps stay the injector US1M and SMAJ33A already in the BOM.
    ---------
    Co-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
    [INJ4.kicad_sch, LS3.kicad_sch, bom_replace_microcore-p.csv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]
2026-09-26 Rev q: NCE4080K gates driven by SLM27524 from V12_RAW (#10)
    Restore Q1-Q7 to NCE4080K and insert four SLM27524CA-DG drivers so the
    STM32 GPIO no longer drives the FET gates. Seven channels are used; the
    spare input is tied to GND. LS clamps and the rev p short fixes stay.
    [INJ4.kicad_sch, LS3.kicad_sch, bom_replace_microcore-q.csv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]
2026-09-26 Rev q DRC triage: stitch F.Cu GND island, document Hellen noise (#11)
    The 473 KiCad 10 violations are Hellen keepout, padstack, pad-G, and silk.
    One frame unconnected item was a 27 mm^2 F.Cu GND island west of the M1
    keepout. A GND stitch via at (131.3, 82) clears it. Unconnected items
    go from 2 to 1 (M2 pad S1 stays). Violation counts stay 473.
    [microcore.kicad_pcb]
2026-09-26 Rev q: clear frame silk DRC and the duplicate INJ1 via (#12)
    Drop the extra /INJ1 via at (174.2, 90.35) and trim or move Q/R/D silk so frame silk_over_copper and silk_overlap clear. Hellen modules, nets, and the drill origin are unchanged.
    [microcore.kicad_pcb]
2026-09-26 Rev q: clear Q2 silk vs M3; refresh hardware leftovers (#13)
    Unlock and move only Q2's reference silk so it no longer overlaps Hellen M3.
    M1/M2/M3, nets, BOM, and the drill origin stay as they are. Status docs now
    match the board on main: fab pack exists, Hellen noise is accepted, and a
    human copper look is still required before any order.
    [microcore.kicad_pcb]
2026-09-26 Rev q: copper-look review notes (docs) (#14)
    Record the read-only gate-driver and GND-stitch check so leftover #3
    can be signed off. No board or fab-pack changes.
